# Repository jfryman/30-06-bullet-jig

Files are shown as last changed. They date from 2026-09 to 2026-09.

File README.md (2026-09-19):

# .30-06 Cartridge Laser-Marking Jig

> ### In memory of Allen Akin
> *September 8, 2026*
>
> This fixture was built to mark the cartridges for his funeral - his name on one
> side, *Spirit in the Sky* on the other. Both are engraved into the base flange,
> so the fixture carries them too. It is published here in the hope that it saves
> someone else a difficult week.
>
> *(If you are reusing this jig, `dedication` and `dedication_edge` at the top of
> `bullet-jig.scad` are yours to change or blank out.)*

A parametric 3D-printable fixture for laser-marking .30-06 Springfield cartridges
consistently, in batches, on two opposing sides.

It replaces the bed-of-rice method: cartridges sit in a cradle that is a true
negative of the SAAMI .30-06 profile, tilted so the engraved surface comes out
**level**, at a known and repeatable height above the laser bed.

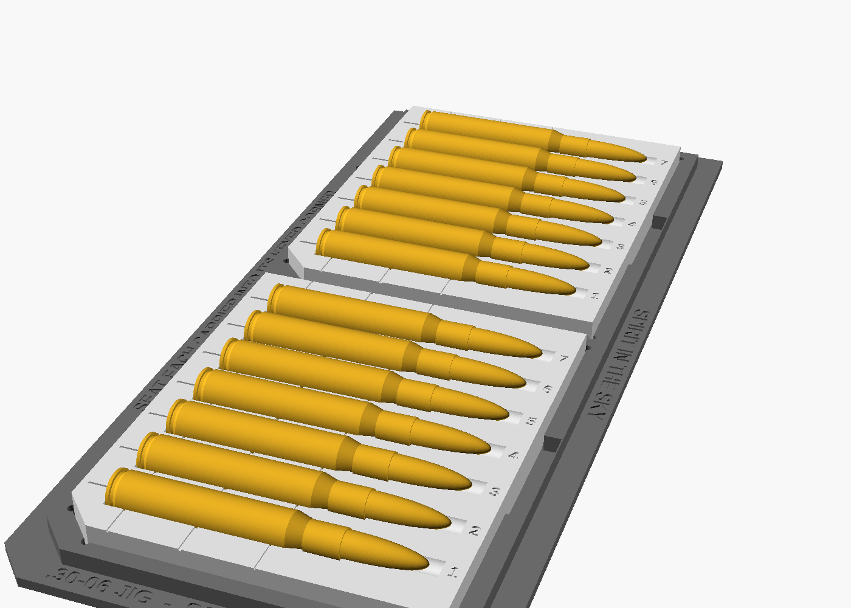
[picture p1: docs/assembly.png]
assembly


---

## How it works

Two parts:

| Part | Role |
|---|---|
| **Base** | Squared and taped to the laser bed **once**, then left alone. Holds the carriers in keyed pockets. |
| **Carrier** | Drops into the base, holds 7 cartridges, lifts out for loading, unloading and flipping. |

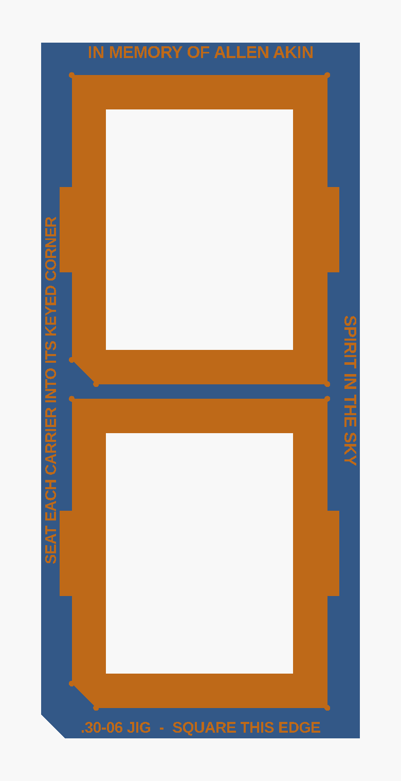
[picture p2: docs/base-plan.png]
base plan


Print several carriers. Load one set off the machine while another set is being
marked, then swap them - the keyed pockets mean a carrier can only ever seat one
way, so the laser program never has to be re-registered.

### The level-surface trick

A .30-06 case body is tapered: Ø11.964 at the head, Ø11.204 at the shoulder. Lay
one in a plain cradle and its top surface **drops 0.380 mm** across the marking
area, which walks the work in and out of focus along the length of the text.

The cradle axis is therefore tilted nose-up by exactly the body half-taper:

```
tilt = atan( (5.982 − 5.602) / (49.00 − 3.40) ) = 0.47746°
```

which cancels the taper, because `top(x) = h₀ + x·tan α + r₀ − k·x` is constant
when `tan α = k`. Measured against the supplied mesh, across the whole case body:

```
 cartridge z   true r    apex height
     3.160     5.9821      5.6585
    12.426     5.9062      5.6597
    21.692     5.8302      5.6609
    30.958     5.7542      5.6621
    40.224     5.6782      5.6634
    49.490     5.6022      5.6646

 non-flatness = 0.0061 mm   (0.380 mm if untilted)
```

Six microns - an order of magnitude below anything an FDM printer can hold, and
irrelevant next to the depth of field of a CO₂ lens.

The tilt is also what guarantees the requirement that a cartridge never nests
deeper than half: the cradle axis sits *at* the carrier top face at the head and
rises from there, so every cartridge lifts straight out with no undercut.

### Key dimensions

| | |
|---|---|
| Marking surface above the carrier top face | **5.660 mm** |
| Marking surface above the laser bed | **18.660 mm** |
| Usable marking window | **6 – 46 mm** from the case head (40 mm) |
| Nest pitch | 16.000 mm |
| Cradle clearance | 0.35 mm radial |

The marking window and its centreline are engraved into the carrier as reference
lines. They cross the cradles, so they read as dashes between nests.

---

## Printing

Prusa XL, PLA, **no supports** - the cradle is a surface of revolution opening
upward, so the model is overhang-free by construction.

| File | Size | Notes |
|---|---|---|
| `stl/carrier-7nest.stl` | 104 × 126 × 10 mm | Print 4–8. Two fit side by side on the XL. |
| `stl/base-14up.stl` | 130.8 × 285.6 × 8 mm | 2 carriers, 14 cartridges per load |
| `stl/base-28up.stl` | 241.6 × 285.6 × 8 mm | 4 carriers, 28 per load - still fits both machines |
| `stl/spray-stand-7nest.stl` | 185 × 33 × 39 mm | Clear-coat drying stand - holds 7 nose-down. See [Clear-coating](#clear-coating). |
| `stl/display-plate-17up.stl` | 212.9 × 77.6 × 9 mm | Drawer organizer - one row of 17 casings that others stack on. See [Displaying the casings](#displaying-the-casings). |
| `stl/display-plate-top.stl` | 271.1 × 144.1 × 9 mm | Chest-top display - two rows of 21, multi-color. See [Displaying the casings](#displaying-the-casings). |

* 0.2 mm layers, 3 perimeters, 15–20 % gyroid infill.
* **Brim on the base.** It is a large thin plate and wants to lift at the corners;
  it has to sit dead flat on the bed.
* Print carriers exactly as modelled, cradles facing up.
* PLA is fine - nothing here gets hot. PETG if you would rather it not scorch.

Both bases fit the Prusa XL's 360 × 360 bed and the xTool P2's 600 × 308 bed. On
the P2 the cartridges run along the 600 mm axis, so the text rasters along the
fast axis and the nests spread across the 308 mm axis.

---

## Setting up on the xTool P2

1. **Square the base** to the gantry using its long straight edge - the flange is
   engraved `SQUARE THIS EDGE`. Tape it down through the flange, outside the walls.
2. **Do not trust nominal coordinates.** A 126 mm PLA part shrinks by a few
   tenths, so the real nest pitch will not be exactly 16.000 mm. Jog the red dot
   to the engraved centreline tick on nest 1 and on nest 7, and derive the pitch
   from the actual printed part. This is the single most important setup step.
3. **Set focus from the marking surface**, nominally 18.660 mm above the bed.
   Verify it on the real thing with calipers - an over-extruded cradle will hold
   the cartridges slightly high.
4. Centre the text on the heavy engraved line, 26 mm ahead of the case head.

---

## Running a batch

1. **Spray the cartridges off the jig**, on a rack, and let them dry. Spraying
   them in the carriers just coats the carriers, which will then mark too.
2. Load carriers, seating every cartridge back against the head stop and every
   carrier into its keyed corner.
3. Run side one on the whole load.
4. Lift the carriers out, roll each cartridge 180° by eye so the first marking
   faces down, reseat.
5. Run side two.
6. Swap in the pre-loaded carriers and unload the finished set while the machine
   is already working on the next.

At 28-up, 150 cartridges is about 6 loads per side.

> On the flip: rolling by eye is good to a few degrees, which is invisible on a
> round cartridge. If you want it exact, engrave both sides in a single program
> with the cartridge rotated between two fixed stops - but for 150 pieces on a
> deadline, by eye is the right call.

---

## Clear-coating

Once both sides are marked, the cartridges get a protective clear topcoat. The
**spray stand** (`spray-stand.scad`, its own model) holds a carrier's worth
**nose-down**, so a single rotating pass covers the whole circumference - both
marked faces at once, no flip-and-redry.

Each round drops nose-first into a bore. The **shoulder** catches on the bore lip
as a self-centring stop - it seats at ~52 mm from the head, just past the 46 mm
marking window, so nothing coating-critical is touched - while the neck stays
guided in the bore below. The head and the full marking window stand up in free
air; the bullet tip hangs through the deck into the open skirt to drain and dry
without touching anything.

Nose-down on purpose: a round balanced head-down on its rim ring is a tall
inverted pendulum and tips at a touch. Hanging by the shoulder with the neck
guided is stable and self-righting.

```bash
openscad -D 'part="stand"' -o stl/spray-stand-7nest.stl spray-stand.scad
```

Prints flat, base down, **no supports** - the funnel and bore open upward. If a
round wobbles, drop `neck_clr`; the skirt height sizes itself so the tip always
clears the bench.

---

## Displaying the casings

For handing the fired casings out as party favours, the **display plate**
(`display-plate.scad`, its own model) is an organizer that carries casings on
their sides. Because a row sits in fixed cradles, more casings **nest in the
valleys between them** and the pile self-stacks into an open pyramid - cannonball
fashion. One model, two footprints via `variant`:

| `variant` | Fits | Holds |
|---|---|---|
| `drawer` (default) | Mini tool-chest **drawer**, 8.5″ wide | one row of **17** |
| `top` | Tool-chest **top**, 10¾″ × 5¾″ | two rows of **21** |

Both are sized to a **[Husky 10 in. Mini Portable Tool Box with 2
Drawers](https://www.homedepot.com/p/Husky-10-in-Army-Green-Metal-Mini-Portable-Tool-Box-with-2-Drawers-690-004-0111/339556529)**
(Home Depot Model # 690-004-0111, Internet # 339556529, Store SKU # 1014987061):
the `drawer` plate to its 8.5″-wide drawers, the `top` plate to its 10¾″ × 5¾″
lid. For a different chest, measure yours and set the footprint at the top of
`display-plate.scad`.

*(The lid closes over an 8 mm inward lip on every edge; the top variant holds the
casings back from it so the lid still shuts. On the 5¾″ (short) axis the two rows
nearly meet in the middle to clear that lip - the depth is the tight dimension,
so keep the plate centred in the well.)*

Two ideas keep the base tidy:

* **Head-to-tail.** A tapered case body laid all one way wedges the stack and
  collides at the rim. Laid head-to-tail, each pair meets fat-body-to-fat-body,
  the pitch is the body diameter, and the valleys run level for the next layer.
  On the drawer the engraved nest numbers zig front/back to cue the lay; the top
  drops the numbers and instead carries **IN MEMORY OF ALLEN AKIN** on the front
  margin and **SPIRIT IN THE SKY** on the back - the way his cartridges carried
  them on opposite sides.
* **A loose fit, on purpose.** These come in and out by hand, so the cradle wraps
  only the lower half (`sink = 0`) and a casing drops **straight in**. Clearance
  is sized to swallow print shrink: a test print came out ~1 mm short on the
  channel, so `axial_clr` leaves the channel comfortably longer than the casing.

```bash
openscad -D 'part="plate"'                     -o stl/display-plate-17up.stl  display-plate.scad
openscad -D 'part="plate"' -D 'variant="top"'  -o stl/display-plate-top.stl   display-plate.scad
```

For the top plate, a ready-to-print slicer project is included:
**`stl/display-plate-top.3mf`**, sliced for the **Original Prusa XL** (multi-tool,
0.4 mm nozzle) as a **multi-color** print - the plate body in one filament and the
two engraved dedications in a contrasting colour, so *In Memory of Allen Akin* and
*Spirit in the Sky* read against the plate. Slice `stl/display-plate-top.stl` for
any other printer.

If a casing still binds, it is a slop problem, not a geometry one - raise
`round_clr` (radial) or `axial_clr` (length). Set `casing_len` to your measured
brass; the render echoes the nominal channel length so you can check it against
calipers. Prints flat, base down, **no supports** - the cradles open upward.

---

## Parameters

Everything is driven from the top of `bullet-jig.scad`.

```bash
openscad -D 'part="carrier"'              -o stl/carrier-7nest.stl bullet-jig.scad
openscad -D 'part="base"'                 -o stl/base-14up.stl     bullet-jig.scad
openscad -D 'part="base"' -D 'pockets_x=2' -o stl/base-28up.stl    bullet-jig.scad
```

The ones worth touching:

| Parameter | Default | |
|---|---|---|
| `clearance` | `0.35` | Raise to `0.50` for fire-formed (once-fired) cases |
| `nest_count` | `7` | Cartridges per carrier |
| `pockets_x`, `pockets_y` | `1`, `2` | Carrier pockets in the base |
| `nest_pitch` | `16` | Centre-to-centre spacing |
| `dedication` | `"IN MEMORY OF ALLEN AKIN"` | Engraved on the base flange; `""` omits it |
| `dedication_edge` | `"SPIRIT IN THE SKY"` | Engraved on the long flange; `""` omits it |

`part` may be `carrier`, `base`, `both`, `demo` (shows cartridges in place) or
`none`.

### Verification

`verify.scad` intersects the supplied `Cartridge.stl` - the real mesh, not the
transcribed profile - against the cradle at its nominal position. The result must
be empty; anything else means the cradle is cut too tight somewhere.

```bash
openscad -o /dev/null verify.scad     # expect: "Current top level object is empty."
```

---

## Safety

Mark **fired brass or inert dummy rounds only.** Do not put live ammunition under
a laser - primers and propellant do not care that the beam is only meant to reach
the case wall.

---

## Credits

The cartridge profile this fixture is cut against was measured from
`Cartridge.stl`, derived from:

> **[".30-06 Springfield"](https://www.printables.com/model/101907-30-06-springfield)**
> by **[is-serp](https://www.printables.com/@isserp)**, licensed
> **[CC BY 4.0 International](https://creativecommons.org/licenses/by/4.0/)**.

The measured profile was cross-checked against published SAAMI .30-06 Springfield
dimensions (rim Ø12.014, body Ø11.964 → Ø11.204, neck Ø8.634, COAL 84.84) before
being used to cut the cradle.

If you publish a remix of this jig, carry that credit forward - CC BY requires it,
and it costs you one line.

## License

| | |
|---|---|
| This jig (`bullet-jig.scad`, `spray-stand.scad`, `display-plate.scad`, `verify.scad`, `stl/`, docs) | [CC BY 4.0](LICENSE) |
| `Cartridge.stl` | CC BY 4.0, © is-serp - see Credits above |

Use it, sell prints of it, modify it; just keep the attribution. To publish under
different terms, replace `LICENSE` and set the license field on your Printables
listing to match - but note you cannot relicense `Cartridge.stl` itself.

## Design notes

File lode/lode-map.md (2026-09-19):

# Lode Map

Index of all lode files. Start here.

```mermaid
flowchart TB
    ROOT["lode/"] --> S["summary.md"]
    ROOT --> T["terminology.md"]
    ROOT --> P["practices.md"]
    ROOT --> PL["plans/"]
    ROOT --> G["geometry/"]
    ROOT --> F["fixture/"]
    ROOT --> PR["process/"]
    ROOT --> PB["publishing/"]
    G --> G1["cartridge-profile"]
    G --> G2["levelling-tilt"]
    G --> G3["lift-out-invariant"]
    F --> F1["carrier"]
    F --> F2["base-tray"]
    F --> F3["registration"]
    F --> F4["spray-stand"]
    F --> F5["display-plate"]
    PR --> PR1["printing-and-machines"]
    PR --> PR2["laser-setup-and-batch"]
    PR --> PR3["verification"]
    PB --> PB1["licensing"]
```

## Top level

| File | Contents |
|---|---|
| [summary.md](summary.md) | One-paragraph snapshot of the whole project |
| [terminology.md](terminology.md) | Cartridge anatomy, fixture parts, process terms |
| [practices.md](practices.md) | Patterns this project holds to |
| [plans/roadmap.md](plans/roadmap.md) | Open work and pending decisions |
| `tmp/` | Session scraps. Git-ignored. |

## geometry/ - the shape of the cavity

| File | Contents |
|---|---|
| [geometry/summary.md](geometry/summary.md) | Domain index, the two invariants |
| [geometry/cartridge-profile.md](geometry/cartridge-profile.md) | `CART` table, datum scheme, deliberate relief |
| [geometry/levelling-tilt.md](geometry/levelling-tilt.md) | The nose-up tilt that cancels body taper |
| [geometry/lift-out-invariant.md](geometry/lift-out-invariant.md) | Why the axis never drops below the top face |

## fixture/ - the physical parts

| File | Contents |
|---|---|
| [fixture/summary.md](fixture/summary.md) | Domain index, part sizes |
| [fixture/carrier.md](fixture/carrier.md) | Nest block: features, markings, invariants |
| [fixture/base-tray.md](fixture/base-tray.md) | Tray: pockets, keying, flange engraving |
| [fixture/registration.md](fixture/registration.md) | Fiducials, the measure-don't-assume doctrine |
| [fixture/spray-stand.md](fixture/spray-stand.md) | Nose-down shoulder-seat stand for clear-coating marked rounds |
| [fixture/display-plate.md](fixture/display-plate.md) | Scalloped casing display; drawer and chest-top (memorial) variants, head-to-tail rows |

## process/ - model to marked cartridges

| File | Contents |
|---|---|
| [process/summary.md](process/summary.md) | Domain index, the pipeline |
| [process/printing-and-machines.md](process/printing-and-machines.md) | Machine budgets, print settings, STL export |
| [process/laser-setup-and-batch.md](process/laser-setup-and-batch.md) | P2 setup, batch workflow, safety |
| [process/verification.md](process/verification.md) | `verify.scad` contract, first-article check |

## publishing/ - licence and distribution

| File | Contents |
|---|---|
| [publishing/summary.md](publishing/summary.md) | Where it lives, repo layout |
| [publishing/licensing.md](publishing/licensing.md) | Two licences, attribution obligations, dedication |

## Reading order for a fresh session

1. [summary.md](summary.md) and [terminology.md](terminology.md)
2. [geometry/levelling-tilt.md](geometry/levelling-tilt.md) - the one idea
   everything else serves
3. [fixture/registration.md](fixture/registration.md) - the one number setup
   depends on
4. [plans/roadmap.md](plans/roadmap.md) - what is open

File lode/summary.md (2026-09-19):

# Project Summary

A parametric OpenSCAD fixture for laser-marking .30-06 Springfield cartridges in
batches, on two opposing sides. It exists to replace a bed-of-rice proof of
concept with something repeatable enough to run 100-150 pieces. The fixture is
two parts: a **base** that is squared and taped to the laser bed once and left
alone, and **carriers** that drop into keyed pockets in the base, each holding 7
cartridges, lifting out for loading, unloading and flipping. The defining design
problem is that a .30-06 case body is tapered, so a cartridge lying in a plain
cradle presents a marking surface that drops 0.380 mm along its length; the
cradle axis is therefore tilted nose-up by exactly the body half-taper, which
cancels the taper and holds the marking surface level to 0.0061 mm. Target
machines are an xTool P2 (600 x 308 bed) and a Prusa XL (360 x 360). A separate
**spray stand** (`spray-stand.scad`) is the downstream companion: it holds a
carrier's worth of marked rounds nose-down, hung by the shoulder in guide bores,
so a rotating pass of clear coat covers both marked faces at once. A stand-alone
**display plate** (`display-plate.scad`) is the end of the line: a scalloped base
that holds finished empty casings on their sides, head-to-tail, so the pile stays
tidy. It has two footprints for a Husky 10 in. mini chest - a drawer organiser
(one row of 17) and a memorial lid-top (two rows of 21, engraved in Allen's
memory). The work is published at github.com/jfryman/30-06-bullet-jig under CC BY
4.0, and is dedicated to Allen Akin.

See [lode-map.md](lode-map.md) for the full index.

Domain entry points:
- [geometry/summary.md](geometry/summary.md) - profile, tilt, and the invariants
- [fixture/summary.md](fixture/summary.md) - carrier and base parts
- [process/summary.md](process/summary.md) - print, verify, set up, run
- [publishing/summary.md](publishing/summary.md) - licence and attribution

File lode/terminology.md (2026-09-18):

# Terminology

Domain language for this project. Cartridge anatomy first, then fixture parts.

## Cartridge anatomy

- **Cartridge** - the complete round: case + primer + powder + bullet. The whole
  thing is what gets marked. Colloquially called "the bullet" in conversation.
- **Bullet** - strictly, only the projectile seated in the case mouth. Not the
  marking surface.
- **Case** - the brass body. Its outer wall is the marking surface.
- **Case head** - the flat base of the cartridge. The axial datum for everything.
- **Rim** - the flange at the head, O12.014 on .30-06. Rides the rim bore.
- **Extractor groove** - the narrow turned groove just ahead of the rim.
  Deliberately not reproduced in the cradle; see
  [geometry/cartridge-profile.md](geometry/cartridge-profile.md).
- **Case body** - the long, slightly tapered section, O11.964 -> O11.204. This
  is the only part that gets marked.
- **Shoulder** - the cone where the body steps down to the neck, at z=49.
- **Neck** - the parallel section gripping the bullet, O8.634.
- **Case mouth** - the open end of the neck, z=63.35.
- **Ogive** - the curved nose of the bullet.
- **COAL** - Cartridge Overall Length. 84.84 mm max for .30-06 per SAAMI.
- **SAAMI** - the US standards body whose published dimensions the measured
  profile was cross-checked against.
- **Fire-formed** - a case that has been fired, so expanded to chamber size.
  Slightly larger than factory; needs more cradle clearance.
- **Headstamp** - markings on the case head. Not used for indexing.

## Fixture parts

- **Base** (or base tray) - the part taped and squared to the laser bed once,
  then left alone. Holds carriers in keyed pockets.
- **Carrier** - the removable block holding 7 cartridges, dropping into a base
  pocket. Several are printed so one loads while another is under the laser.
- **Nest** - one cartridge position in a carrier.
- **Cradle** - the cavity of one nest; a true negative of the cartridge profile.
- **Apex line** - the topmost line along the cartridge, where the beam lands.
  Holding this level is the point of the tilt.
- **Marking window** - the usable span of case body, 6-46 mm from the case head.
- **Head stop** - the wall the case head butts against; the axial datum.
- **Rim bore** - the straight section of cradle the rim rides in.
- **Eject slot** - through-slot at the neck; push a round up from underneath.
- **Tip channel** - relief past the bullet nose so an over-long round cannot bind.
- **Key corner** - the 45 degree chamfer that makes a carrier seat one way only.
- **Flange** - the flat border of the base, for taping down and squaring.
- **Fiducial / tick** - engraved centreline mark used to align the laser to the
  real printed part rather than to nominal coordinates.
- **Pitch** - nest centre-to-centre spacing, 16.000 mm nominal.

## Process

- **Laser spray / marking spray** - CerMark-type coating that bonds to metal
  under a CO2 beam. Applied before loading, never on the jig.
- **Clear coat / topcoat** - a protective clear finish rattle-canned over the
  finished marks, after marking. A different coating at a different step from the
  marking spray; applied with the round in the spray stand, not the jig.
- **Spray stand** - the companion fixture that holds a carrier's worth of rounds
  nose-down for clear-coating. See
  [fixture/spray-stand.md](fixture/spray-stand.md).
- **Display plate** - a stand-alone display base (not a pipeline fixture) that
  holds finished empty cases lying on their sides in a scalloped row inside a
  tool-chest drawer. See [fixture/display-plate.md](fixture/display-plate.md).
- **Head-to-tail** - laying cases in alternating directions so each adjacent
  pair's radii sum to a constant along the tapered body; gives level valleys and
  packs tighter than one direction (which would collide at the rim). The display
  plate's base row is laid this way.
- **Open pyramid** - the display stacking scheme: the plate fixes only the base
  row; each further layer nests by gravity in the valleys of the layer below.
- **Shoulder seat** - how the spray stand holds a round: dropped nose-first, the
  shoulder cone catches on a bore lip while the neck is guided in the bore below.
  Nose-down because nose-up (rim ring, no upper guide) is too tippy.
- **Fast axis** - the laser's raster direction (X on the P2). Text runs along it.
- **First article** - the first part off the printer, checked before a batch.

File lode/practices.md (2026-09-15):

# Practices

Patterns this project holds to. Most were paid for once already.

## Verify against the real artefact, not your transcription

`CART` is a hand-transcribed profile. The test that matters intersects the
**actual `Cartridge.stl` mesh** against the cradle, so a typo in the table is
caught by geometry rather than by proofreading. See
[process/verification.md](process/verification.md).

Corollary: when measuring a coarse mesh, evaluate at its **true vertex rings**.
Sampling arbitrary narrow bands returns empty sets and looks like a code bug.

## Manifold is not correct

A valid, watertight, "Simple: yes" render proves only that the solid is
well-formed. An eject slot cutting sideways into neighbouring nests passed every
automated check. **Render an image and look at it** after any change to
placement, rotation, or text.

## Derive constants; never type them

```openscad
body_k = (5.982 - 5.602) / (49.00 - 3.40);
tilt   = atan(body_k);        // not 0.4775
```

If the profile changes, the tilt follows. A typed-in tilt silently decouples from
the geometry it is supposed to cancel.

## Coordinate-frame discipline

Two traps, both hit once:

- **Cartridge z is not carrier X.** They differ by `head_margin`. Convert.
- **After `rotate([0, 90 - tilt, 0])`, local +X is "down"**, not local Y. Work
  out the axis mapping before writing a cube into a rotated frame.

## Empirical alignment beats nominal coordinates

Printed parts shrink. Rather than chase tolerances, engrave fiducials and align
the machine to the **real part**. See
[fixture/registration.md](fixture/registration.md). The corollary is that every
fiducial needs its nominal value documented so a measured deviation is
meaningful.

## Cheap checks gate expensive ones

Order any check procedure so a failure at step 1 saves the work of steps 2-6.
Likewise, structure parts so a likely failure is a **cheap** reprint: `clearance`
and `pocket_clr` problems both reprint the carrier only, never the base.

## Relieve what you cannot print reliably

The extractor groove is not reproduced. A printed bump inside a 0.8 mm groove
would rock the cartridge and destroy the levelness the design depends on.
Prefer a clean relieved datum over a faithful copy of a feature FDM cannot hold.

## Parameterise what a downstream user would change

The dedication is a parameter, not a string literal, because the model is
published for others. Same for `clearance`, `nest_count`, `pockets_*`.

## Assert only what you verified

Do not state a licence version you have not seen; do not quote print times you
have not measured. Fetch canonical legal text rather than reproducing it.

## Build hygiene

- Export with `--export-format=binstl`. ASCII STL is ~3.5x larger.
- Keep the `echo()` dimension block current; it is a free regression check on
  every render.
- Regenerate **all** STLs after a source change, even parts you believe are
  unaffected.

## Related

- [summary.md](summary.md)
- [lode-map.md](lode-map.md)

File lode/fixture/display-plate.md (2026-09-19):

# Display plate

A loose organizer, not a pipeline fixture and not a precision cradle. Fired empty
**casings** (no bullet, ~63 mm to the mouth) are dropped on their sides into a
scalloped plate. Each cradle holds one casing; a row seats a base row, and
further casings nest in the valleys between them so the pile self-stacks into an
**open pyramid** (`layer_rise = sqrt(3) * r_centre` ~ 9.95 mm per layer). Source
is `display-plate.scad` at the repo root; one model, two footprints via `variant`.

These are **party favours**: the aim is tidy organisation, so every casing must
drop in and lift out freely - the opposite instinct from the jig. It shares only
the cartridge profile (the [CART](../geometry/cartridge-profile.md) table,
truncated at the case mouth).

## Two variants (`variant`)

| `variant` | Footprint | Rows x count | STL |
|---|---|---|---|
| `drawer` | 8.5" drawer -> `drawer_w - 2*fit_clr` wide, depth snug to one row | 1 x 17 | `stl/display-plate-17up.stl` |
| `top` | 10.75 x 5.75" chest top (`top_w` x `top_d`), minus `pullback` per edge | 2 x 21 | `stl/display-plate-top.stl` |

Both footprints are sized to a **Husky 10 in. Mini Portable Tool Box with 2
Drawers** (Home Depot Model # 690-004-0111, Internet # 339556529, Store SKU #
1014987061): the drawer plate to its 8.5" drawers, the top plate to its
**10.75 x 5.75"** lid (measured off the real chest).

`drawer` is the default so a bare render reproduces the shipped drawer plate.
`stack_gap` differs (0.60 drawer for finger room, 0.25 top to make the count).

```mermaid
flowchart TB
    V{variant} -->|drawer| DR["8.5 in drawer<br/>1 row x 17, nests into a pyramid"]
    V -->|top| TP["10.75 x 5.75 in lid<br/>2 rows x 21 = 42, single layer"]
```

### The lid lip - why the top is 2 x 21

The lid closes over an inward **lip, `lid_lip = 8` mm on every edge**. Anything
protruding under it stops the lid, so the casings are held `keepout = lid_lip +
lip_clr` back from the lid opening (the plate itself still fills the well). Two
asserts (`lip_gap_x`, `lip_gap_y`) prove the brass clears the lip; the `echo`
reports the margin.

- **Width (10.75", roomy):** count is maximised inside the keepout -> **21** per
  row, clearing the lip by ~4.6 mm.
- **Depth (5.75", tight):** two rows of 63.25 mm casings need 126.5 mm; the clear
  span inside the lip is only ~130 mm. So the rows **pack tight** (`row_pitch =
  casing_len + row_gap`, ~0.5 mm gap, channels may merge at the centre) and centre
  on the lid, clearing the lip by only **~1.5 mm**. `pullback` is small (1 mm) so
  the plate cannot slide far and eat that margin. A single row is the safe
  fallback if the depth margin is unacceptable.

## Loose by design - the slop knobs

The first cut gripped too hard to accept a casing without angling it in. Fixed:

- **`sink = 0`.** The cradle wraps only the **lower half** of the casing, so the
  opening at the surface is the full casing diameter and it drops **straight
  down**. Any positive `sink` grips past the equator (retention, but you must snap
  it in) - keep 0 for party favours.
- **Clearance sized to swallow print shrink.** `round_clr = 0.50` radial;
  `axial_clr = 2.00` extends the channel to **65.55 mm** so it clears the measured
  **63.25 mm** casing by 2.3 mm. A test print came out ~1 mm short of nominal on
  channel length (~1.2 % shrink), so the real margin is ~1.3 mm. Raise
  `round_clr` / `axial_clr` if a printer runs tighter; an assert guards
  `channel_len >= casing_len + 0.5`. The `echo` reports the nominal length for a
  caliper check.

## What keeps a row uniform

**Alternating head-to-tail** cancels the body taper (r 5.982 -> 5.602): each pair
meets fat-body-to-fat-body, the pitch is the body diameter, and the valleys run
level. Packs tighter than one-way (which collides at the rim, O12.014). An assert
guards `pitch >= contact_d`.

**A symmetric negative.** Each cradle is the casing profile of revolution grown by
`round_clr`, end caps pushed out by `axial_clr/2`, laid along Y and unioned with
its mirror (`cradle_cut(cy)`), so a casing seats level whichever way it points.

## Layout

- `count` across the width: drawer maximises inside the side walls, top maximises
  inside the lid keepout; then centred (`nest_cx`).
- Rows front-to-back (`row_cy(j)`, `row_pitch`): the drawer's single row sits at
  `end_margin`; the top's two rows pack tight (`casing_len + row_gap`) and centre
  on the lid. An assert stops the casings themselves overlapping.
- `plate_th = sink + (rim_r + round_clr) + floor` ~ 9.0 mm (thin, since sink 0).

## Markings (`markings` -> `drawer_markings` / `top_markings`)

- **Drawer**: casing numbers in the flat band beyond each casing's head end,
  alternating so they zig and cue the head-to-tail lay; `title` on the front
  face, `dedication` on the back.
- **Top**: a memorial display - **no numbers**. The two rows nearly meet at the
  centre on the short lid, so there is no centre band; `dedication` engraves on
  the **front** margin and `dedication_edge` on the **back** ("IN MEMORY OF ALLEN
  AKIN" / "SPIRIT IN THE SKY", the pair the funeral cartridges carried on opposite
  sides). Engraved (recessed), so being near the edge does not foul the lid lip.

## Print

Flat, base down, **no supports** - the cradles open upward.

A ready-to-print slicer project ships for the top variant:
`stl/display-plate-top.3mf`, a PrusaSlicer project for the **Original Prusa XL**
(multi-tool, 0.4 mm nozzle), sliced **multi-colour** (cream body, orange
lettering) so the two dedications print in a contrasting filament. It carries the
corrected `variant="top"` mesh; the `.stl` beside it is for any other printer.

## Related

- [../geometry/cartridge-profile.md](../geometry/cartridge-profile.md) - the
  `CART` profile this mirrors (truncated at the mouth) and the uniform-offset
  doctrine (here relaxed for a loose fit)
- [spray-stand.md](spray-stand.md) - the other stand-alone companion `.scad`

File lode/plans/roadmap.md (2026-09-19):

# Roadmap

Current open work. Delete items as they close; this file is state, not history.

The marking jig, the spray stand, and both display plates are built and validated
in use. What is left is publishing and one standing throughput option.

## Not started

- **Printables listing.** The GitHub repo is live; the Printables publication is
  not. Licence and attribution obligations are recorded in
  [../publishing/licensing.md](../publishing/licensing.md).

## Available but not committed

- **28-up base.** `stl/base-28up.stl` exists (`pockets_x = 2`, 241.6 x 285.6) and
  fits both machines. Doubles throughput per load at the cost of a larger base
  print. Default remains the 14-up base to keep the critical-path print short.

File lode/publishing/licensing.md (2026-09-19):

# Licensing and Attribution

```mermaid
flowchart TB
    UP[".30-06 Springfield<br/>by is-serp<br/>CC BY 4.0"] -->|source mesh| CART["Cartridge.stl<br/>stays CC BY 4.0"]
    CART -->|profile measured from| JIG["bullet-jig.scad + STLs<br/>CC BY 4.0"]
    JIG --> OBL["Attribution obligation<br/>carries forward"]
```

## Two licences, one repo

| Covers | Licence |
|---|---|
| `bullet-jig.scad`, `spray-stand.scad`, `display-plate.scad`, `verify.scad`, `stl/`, `docs/` | CC BY 4.0 |
| `Cartridge.stl` | CC BY 4.0, (c) is-serp |

`LICENSE` holds the canonical CC BY 4.0 legal text, fetched from
`creativecommons.org/licenses/by/4.0/legalcode.txt` rather than retyped.

## The upstream attribution

The cartridge profile was measured from a third-party mesh:

> **".30-06 Springfield"** by **is-serp**
> https://www.printables.com/model/101907-30-06-springfield
> Licensed CC BY 4.0 International

Recorded in three places, all of which must stay in sync: the README Credits
section, the README licence table, and the `bullet-jig.scad` header.

## Contracts

- **`Cartridge.stl` cannot be relicensed.** If the project licence ever changes,
  the mesh stays CC BY 4.0 and the attribution stays. The README licence table
  says so explicitly.
- Any remix must carry the is-serp credit forward - CC BY requires it.
- The Printables listing's licence field must match `LICENSE`.

## Dedication

The fixture is dedicated to **Allen Akin**, who died 8 September 2026; it was
built to mark cartridges for his funeral, his name on one side and *Spirit in
the Sky* on the other. The dedication appears in the README, the
`bullet-jig.scad` header, and engraved into two flanges of the base.

It is **parameterised, not hardcoded**, so anyone reusing the jig can substitute
their own words or blank it:

```openscad
dedication      = "IN MEMORY OF ALLEN AKIN";   // top flange, "" omits
dedication_edge = "SPIRIT IN THE SKY";         // right flange, "" omits
```

## Lessons learned

Do not assert a licence version you have not seen. Printables' API reports only
`"abbreviation": "CC-BY"` with no version; the "4.0 International" came from the
model page itself. For legal text, fetch the canonical copy rather than
reproducing it from memory.

Printables blocks scripted page fetches (Cloudflare 403), but its GraphQL API
answers anonymously:

```bash
curl -sS 'https://api.printables.com/graphql/' \
  -H 'content-type: application/json' -H 'origin: https://www.printables.com' \
  --data '{"query":"query($id:ID!){print(id:$id){name license{name abbreviation} user{publicUsername}}}","variables":{"id":"101907"}}'
```

## Related

- [../geometry/cartridge-profile.md](../geometry/cartridge-profile.md)
- [summary.md](summary.md)

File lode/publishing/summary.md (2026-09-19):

# Publishing

The project is published as an open model. Two obligations attach to that: the
upstream mesh's licence, and the project's own.

- [licensing.md](licensing.md) - licences, attribution, and what may be
  relicensed

## Where it lives

| | |
|---|---|
| Git remote | `git@github.com:jfryman/30-06-bullet-jig.git` (branch `master`) |
| Printables | not yet listed |

Pushes go over SSH. `gh` is not authenticated on this machine, and the HTTPS
remote cannot authenticate non-interactively.

## Repo layout

```
bullet-jig.scad     parametric marking jig, base + carrier
spray-stand.scad    clear-coat drying stand (own model)
display-plate.scad  casing display, drawer + chest-top variants (own model)
verify.scad         automated fit test, must render empty
Cartridge.stl       reference mesh (third-party, CC BY 4.0)
stl/                carrier-7nest, base-14up, base-28up, spray-stand-7nest,
                    display-plate-17up, display-plate-top (+ .3mf for the XL)
docs/               renders (assembly, base plan, carrier)
lode/               this knowledge base (lode/tmp/ is git-ignored)
LICENSE             CC BY 4.0
```

## Related

- [../process/printing-and-machines.md](../process/printing-and-machines.md)

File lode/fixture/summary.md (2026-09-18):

# Fixture

The two physical parts and how they relate.

```mermaid
flowchart TB
    BED["Laser bed"] -->|taped + squared once| BASE["Base tray<br/>130.8 x 285.6 x 8"]
    BASE -->|keyed pockets| C1["Carrier 1<br/>104 x 126 x 10"]
    BASE -->|keyed pockets| C2["Carrier 2"]
    C1 --> N["7 nests each<br/>16 mm pitch"]
    C2 --> N
    SPARE["Spare carriers<br/>loaded off-machine"] -.->|swap| BASE
```

The base never moves once taped. Carriers are consumable fixturing: print
several, load one set while another is under the laser, swap them. A separate
**spray stand** holds a carrier's worth of rounds nose-down for clear-coating
after marking; it is downstream of the base/carrier, not part of the assembly.

## Files

- [carrier.md](carrier.md) - the removable nest block
- [base-tray.md](base-tray.md) - the taped-down tray
- [registration.md](registration.md) - keying, fiducials, and why nominal
  coordinates must not be trusted
- [spray-stand.md](spray-stand.md) - nose-down shoulder-seat stand for clear-coating
- [display-plate.md](display-plate.md) - scalloped base for stacking finished
  empty casings; drawer (1 row) and chest-top (2 rows) variants

## Part sizes

| Part | Size | Config |
|---|---|---|
| `stl/carrier-7nest.stl` | 104 x 126 x 10 | `nest_count = 7` |
| `stl/base-14up.stl` | 130.8 x 285.6 x 8 | `pockets_x=1, pockets_y=2` |
| `stl/base-28up.stl` | 241.6 x 285.6 x 8 | `pockets_x=2, pockets_y=2` |
| `stl/spray-stand-7nest.stl` | 185 x 33 x 39 | `nest_count = 7` (own `.scad`) |
| `stl/display-plate-17up.stl` | 212.9 x 77.6 x 9.0 | 8.5" drawer -> 17 up, loose fit (own `.scad`) |
| `stl/display-plate-top.stl` | 271.1 x 144.1 x 9.0 | 10.75x5.75" chest top -> 2 rows of 21, multi-color (`variant="top"`) |

## Related

- [../geometry/summary.md](../geometry/summary.md) - what shapes the nests
- [../process/printing-and-machines.md](../process/printing-and-machines.md)

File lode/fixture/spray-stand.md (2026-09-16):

# Spray stand

A companion fixture, separate from the marking jig. After a batch is
laser-marked, the rounds are stood **nose-down** in the spray stand and given a
protective clear coat (a rattle-can topcoat over the CerMark marks). Source is
`spray-stand.scad` at the repo root; production STL is
`stl/spray-stand-7nest.stl`. It shares nothing with the jig but the cartridge
profile it seats against.

## Why nose-down, vertical

A loaded round is a closed cartridge (bullet seated) - it can only be held
externally. Standing it vertical means one **rotating pass coats the whole
circumference**, so both opposing marked faces are covered without a
flip-and-redry cycle a horizontal cradle would force. The
[marking window](../geometry/cartridge-profile.md) (6-46 mm from the head)
stands in free air well above the deck, fully exposed. This part does **not**
use the jig's [levelling tilt](../geometry/levelling-tilt.md) - a drying round
only has to stand still, not present a level surface.

**Nose-down, not nose-up.** A round balanced head-down on its rim ring is a tall
inverted pendulum (COM ~40 mm up over a ~12 mm base) and tips at a touch - the
first nose-up cone-seat attempt failed exactly here. Dropped nose-first into a
bore instead, the slender bullet and neck lead in and the round hangs by its
shoulder, guided along the neck, which is stable and self-righting.

## The shoulder seat

The round drops nose-first into a lead-in funnel over a straight guide bore.

```mermaid
flowchart TB
    R["Round, nose-down<br/>head + marking window up, exposed"] --> SH["Shoulder cone catches on bore lip<br/>self-centring axial stop, z 51.96 from head"]
    R --> NECK["Neck captured in guide bore below<br/>resists cocking, self-rights"]
    SH --> LIP["Funnel lip = seat, cs_depth below deck top"]
    NECK --> DRAIN["Bore runs through into the open skirt<br/>coating drains, bullet hangs free"]
```

Contract, all derived in the `.scad` from the CART shoulder/neck dimensions:
- Guide bore radius `bore_r = neck_r(4.317) + neck_clr(0.4)` = 4.717
  (O9.43). The neck (O8.634) drops through; the shoulder (widening past it)
  cannot, so it seats.
- The shoulder catches where its cone reaches `bore_r`: **z 51.96 mm from the
  head**. Two asserts guard the design: `bore_r < shoulder top r` (so it seats
  at all) and `seat_zfh > window_to(46)` (so the seat never shadows the marking
  window). If you widen `neck_clr` a lot, re-check the second assert.
- Seat is a ring on the bore lip (cone-on-edge): minimal contact, on the
  unmarked shoulder just past the window, self-centring.
- The bore runs straight through the deck into the open skirt cavity, so coating
  drains out and the bullet tip hangs free.
- Anti-tip: the neck is guided over ~11 mm of bore below the seat at 0.4 mm
  clearance -> the round can only cock ~2 degrees, and gravity re-seats it. This
  is the whole reason nose-down is stable where nose-up was not.

## Structure and print

- Single row of `nest_count = 7` seats at `nest_pitch = 26` mm.
- Deck `185 x 33 x 18`; the bore runs through it. Lifted on a skirt whose height
  is **computed** (`skirt_h`) so the bullet tip (hanging ~17.9 mm below the deck
  bottom) clears the bench by `tip_clr = 3` mm. Overall height ~38.9 mm.
- Skirt corners solid for rigidity; long sides windowed for drainage, airflow
  and finger access. Bullet tips hang in the open windowed cavity.
- Prints flat, base down, **no supports**: the funnel and bore are open upward.
- Seat numbers 1-7 on the deck front match the [carrier](carrier.md) nest
  numbers; `title` on the skirt face and `dedication` on the deck are parametric.

## Related

- [carrier.md](carrier.md) - where the rounds come from; nests numbered to match
- [../geometry/cartridge-profile.md](../geometry/cartridge-profile.md) - the
  shoulder, neck and marking-window dimensions this seats against
- [../process/summary.md](../process/summary.md) - marking spray vs. this clear
  coat are different coatings at different steps

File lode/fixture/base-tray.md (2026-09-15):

# Base Tray

Squared and taped to the laser bed **once**, then left alone. Everything
downstream is referenced off it, so its flatness is load-bearing.

## Construction

```openscad
pocket_x = carrier_len + 2 * pocket_clr;   // 104.8
pocket_y = carrier_y   + 2 * pocket_clr;   // 126.8
span_x = pockets_x * pocket_x + (pockets_x - 1) * divider;
span_y = pockets_y * pocket_y + (pockets_y - 1) * divider;
base_x = span_x + 2 * base_wall + 2 * flange;
base_y = span_y + 2 * base_wall + 2 * flange;
base_h = base_floor + pocket_depth;        // 3 + 5 = 8
```

A 3 mm floor with 5 mm walls standing 5 mm proud, plus an 8 mm flat flange all
round for taping and squaring.

```mermaid
flowchart TB
    F["Flange 8 mm<br/>tape + square here"] --> W["Wall 5 mm<br/>pocket sides"]
    W --> P["Pocket, 0.4 mm/side<br/>carrier drops in"]
    P --> FL["Floor 3 mm"]
    FL --> WIN["Window<br/>inset 14 mm"]
    WIN --> EJ["Push rounds up<br/>through carrier eject slots"]
```

## Features

- **Pockets**, one per carrier, `pocket_clr = 0.4` per side, `pocket_depth = 5`.
  The carrier is 10 mm thick, so 5 mm stands proud to grip.
- **Key corner** - 45 deg chamfer, `key_chamfer = 10`, on each pocket *and* on
  the overall outline. Breaks every symmetry, so a carrier seats one way only.
- **Corner relief** - r = 1.2 cylinders at each pocket vertex so a slightly
  bulged carrier corner cannot wedge.
- **Floor windows**, inset 14 mm. Save print time and let you push cartridges up
  from underneath through the carrier's eject slots.
- **Finger notches**, 35 mm wide in the end walls, for lifting a loaded carrier.

## Flange engraving

All four flanges are used. Engraved, never raised - raised lettering would stop
the base taping down flat.

| Flange | Text | Source |
|---|---|---|
| bottom (X) | `.30-06 JIG  -  SQUARE THIS EDGE` | fixed |
| left (Y) | `SEAT EACH CARRIER INTO ITS KEYED CORNER` | fixed |
| top (X) | `IN MEMORY OF ALLEN AKIN` | `dedication` |
| right (Y) | `SPIRIT IN THE SKY` | `dedication_edge` |

The dedication is parameterised so anyone reusing the jig can change or blank it
(`""` omits). See [../publishing/licensing.md](../publishing/licensing.md).

## Invariants

- **The base must sit dead flat.** It is a large thin plate; print with a brim.
  If a corner rocks, every height measurement below it is meaningless.
- Flange text must fit inside `base_x`. At `size = 4.5`-`5`, a ~45 character
  string overflows the 130.8 mm 14-up base. Check a top-down render after
  editing any flange string.
- Engrave, never emboss, on the flange.

## Related

- [carrier.md](carrier.md)
- [registration.md](registration.md)

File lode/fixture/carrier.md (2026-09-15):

# Carrier

The removable block holding 7 cartridges. Drops into a keyed base pocket, lifts
out for loading, unloading and flipping.

## Geometry

```openscad
carrier_y = nest_count * nest_pitch + 2 * side_margin;   // 7*16 + 14 = 126
function nest_y(i) = side_margin + nest_pitch / 2 + i * nest_pitch;
```

Size 104 x 126 x 10 mm. Top face sits **on the cartridge centreline** - that is
what makes the nest exactly half-depth.

| Feature | Extent | Purpose |
|---|---|---|
| Head stop | X = 0 .. 9.8 | Solid band; case head butts it. Axial datum. |
| Nest cradle | from X = 9.8 | Profile negative, see [../geometry/cartridge-profile.md](../geometry/cartridge-profile.md) |
| Eject slot | cartridge z 54..64 | Through-slot at the neck; push rounds up from below |
| Tip channel | cartridge z 78..88 | Relief past the nose, r = 3.0 |
| Solid band | X = 98 .. 104 | Carries the nest numbers |
| Bottom chamfer | 0.8 mm | Defeats elephant's foot so it seats flat in the pocket |

```mermaid
flowchart LR
    HS["Head stop<br/>X 0-9.8"] --> W1["Window start<br/>16"]
    W1 --> WC["Window centre<br/>36 (heavy line)"]
    WC --> W2["Window end<br/>56"]
    W2 --> EJ["Eject slot<br/>64-74"]
    EJ --> TC["Tip channel<br/>88-98"]
    TC --> NUM["Nest numbers<br/>98-104"]
```

## Engraved markings

All cut `mark_depth = 0.5` into the top face:

- **Three transverse reference lines** at 6, 26 and 46 mm from the case head
  (the heavy one at 26 is the window centre). They cross the cradles, so they
  read as **dashes between nests**.
- **A centreline tick per nest** on the head-end solid band, X = 2..8.
- **A nest number per nest** on the tip-end solid band, X ~ 101.

These exist so the laser is aligned to the real printed part. See
[registration.md](registration.md).

## Invariants

- Top face is the parting plane at the cartridge centreline. Do not thicken the
  carrier without moving the nest axis with it.
- No supports, cradles facing up - guaranteed by
  [../geometry/lift-out-invariant.md](../geometry/lift-out-invariant.md).
- Anything cut past `tip_to` must leave the X 98..104 band solid or the nest
  numbers land in mid-air. `tip_to` is in **cartridge z**; carrier X is
  `head_margin + z`, so `tip_to = 88` puts the channel end at X = 98.

## Lessons learned

Cartridge z and carrier X differ by `head_margin`. Conflating them once pushed
the tip channel 4 mm past the end face. Always convert.

## Related

- [base-tray.md](base-tray.md)
- [registration.md](registration.md)

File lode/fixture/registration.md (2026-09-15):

# Registration and Fiducials

How the laser finds the work, and the one measurement the whole setup depends on.

## The doctrine

> **Never program nominal coordinates. Measure the printed part.**

A 126 mm PLA carrier shrinks by a few tenths, so its real nest pitch is not
16.000 mm. Worse, the shrinkage is in the *carrier itself*, so no amount of
precision in the base can correct it. The fix is to make alignment empirical:
engraved fiducials on the carrier, which the operator jogs the red dot to.

```mermaid
flowchart TB
    KEY["Keyed corner<br/>one seating orientation"] --> SEAT["Carrier seated<br/>pushed into the key"]
    SEAT --> T1["Jog to nest 1 tick<br/>nominal Y = 15.000"]
    SEAT --> T7["Jog to nest 7 tick<br/>nominal Y = 111.000"]
    T1 --> SPAN["Measured span<br/>nominal 96.000"]
    T7 --> SPAN
    SPAN --> DIV["Divide by 6 gaps"]
    DIV --> PITCH["REAL pitch -> program"]
```

## The numbers

| | |
|---|---|
| nest 1 centreline tick | Y = 15.000 mm from the carrier edge |
| nest 7 centreline tick | Y = 111.000 mm |
| span | 96.000 mm across **6** gaps |
| window centre (heavy line) | X = 36 mm from the carrier head-end face |

Derived from `nest_y(i) = side_margin + nest_pitch/2 + i*nest_pitch`, so
`nest_y(0) = 15` and `nest_y(6) = 111`.

## The off-by-one

**Divide the span by 6, not 7.** Seven nests, six gaps. Dividing by the nest
count instead of the gap count yields 13.71 mm and puts the program 2.67 mm out
per nest - a miss, not a rounding error, and one that survives a casual check
because the wrong answer still looks plausibly like "about 16".

## Registration chain

- **Rotation and translation** come from the keyed pocket. Always seat a carrier
  *into* its key corner; the pocket has 0.4 mm/side of clearance, so consistency
  comes from always pushing the same way, not from the fit being tight.
- **Y (across nests)** is the critical direction: error here walks the text off
  the apex crown. It is absorbed by measuring the tick span.
- **X (along the cartridge)** is tolerant; error just shifts text along the case.
- **Z** is `18.660 mm` above the bed, verified with calipers, not assumed.

## Flip registration

The 180 degree flip for side two is done **by eye** - roll the round until the
first marking faces down. Deliberate: rolling is accurate to a few degrees, which
is invisible on a round cartridge, and any positive indexing scheme adds a part
to handle 300 times. The cradle lets the round spin freely about its own axis,
which is what makes this work.

## Related

- [carrier.md](carrier.md) - where the fiducials live
- [base-tray.md](base-tray.md) - the keyed pockets
- [../process/laser-setup-and-batch.md](../process/laser-setup-and-batch.md)

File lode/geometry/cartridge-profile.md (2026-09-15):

# Cartridge Profile

The cradle is cut as a true negative of a measured .30-06 profile, held in the
`CART` table in `bullet-jig.scad`.

## The table

Columns are `[ axial position from case head, radius, extra local relief ]`.
All values mm. The profile was measured off `Cartridge.stl` and cross-checked
against published SAAMI .30-06 dimensions (rim O12.014, body O11.964 -> O11.204,
neck O8.634, COAL 84.84).

```openscad
CART = [
  //  z       r       relief
  [ -0.20,  6.007,  0.00 ],   // head face, 0.2 mm axial clearance
  [  3.40,  6.007,  0.00 ],   // straight rim bore (extractor groove relieved)
  [  3.40,  5.982,  0.00 ],   // case body, head end
  [ 49.00,  5.602,  0.00 ],   // case body, shoulder end
  [ 53.30,  4.317,  0.30 ],   // shoulder / neck junction
  [ 63.35,  4.317,  0.30 ],   // case mouth
  [ 63.35,  3.925,  0.50 ],   // bullet bearing surface
  // ... ogive points to [ 84.84, 0.300, 0.50 ]
];
```

The cavity is a solid of revolution built from the table with clearance added
radially:

```openscad
module cradle_solid() {
  pts = concat(
    [ [ 0, CART[0][0] ] ],
    [ for (p = CART) [ p[1] + clearance + p[2], p[0] ] ],
    [ [ 0, CART[len(CART) - 1][0] ] ]
  );
  rotate_extrude($fn = nest_fn) polygon(pts);
}
```

## Datum scheme

```mermaid
flowchart LR
    H["Case head<br/>z = 0"] -->|butts against| HS["Head stop wall<br/>AXIAL DATUM"]
    R["Rim O12.014"] -->|rides| RB["Rim bore<br/>straight, z = -0.2 .. 3.4"]
    B["Case body cone"] -->|seats in| BC["Body cradle<br/>z = 3.4 .. 49"]
    RB --> LOC["Located on two datums,<br/>as a chamber does"]
    BC --> LOC
```

The cartridge is located by the **rim bore and the body cone only**. Everything
past the shoulder carries extra relief and is not a locating surface.

## Deliberate departures from the real shape

These are design decisions, not omissions. Do not "fix" them:

- **The extractor groove is not reproduced.** The rim rides a plain straight bore
  from z = -0.20 to 3.40 and the groove is left in free air. Reproducing a
  0.8 mm wide groove invites a printed bump inside it, which would rock the
  cartridge and destroy the levelness the whole design is built on.
- **Extra relief past the shoulder** (0.30 mm at the neck, 0.50 mm on the
  bullet). This lets a fire-formed case, or a case with no bullet seated at all,
  still drop in. A blank-fired case simply sits in the case portion of the cradle
  with the bullet portion empty.
- **0.2 mm axial clearance at the head face** so the round drops in without
  binding, then pushes back against the head stop.

## Contracts

- **Uniform radial offset means uniform contact.** Because every point is offset
  by the same `clearance`, the cartridge settles by exactly `clearance` and
  contacts along its whole length at once. This is what makes the seated height
  a fixed, repeatable offset rather than a rattle.
- `clearance = 0.35` suits factory brass; **0.50** for fire-formed cases.
- Changing `CART` invalidates `body_k` and therefore the tilt. See
  [levelling-tilt.md](levelling-tilt.md).

## Lessons learned

The supplied mesh is coarse in the cylindrical region - vertex rings only every
~9 mm - so naive vertex sampling in narrow bands returns empty sets. Evaluate at
the actual ring positions instead; the surface between them is a straight cone,
so ring values bound the whole span.

## Related

- [levelling-tilt.md](levelling-tilt.md)
- [../process/verification.md](../process/verification.md)
- [../publishing/licensing.md](../publishing/licensing.md) - the mesh is CC BY

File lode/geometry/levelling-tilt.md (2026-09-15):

# The Levelling Tilt

The central idea of the fixture. A .30-06 case body is tapered, so a cartridge
lying in a plain cradle presents a marking surface that is **not level**, which
walks the work in and out of focus along the length of the text.

## The problem

```mermaid
flowchart TB
    subgraph PLAIN["Plain cradle - axis horizontal"]
        P["apex drops 0.380 mm<br/>over the 45.6 mm body"]
    end
    subgraph TILTED["Cradle tilted nose-up by atan(k)"]
        T["apex constant<br/>0.0061 mm non-flatness"]
    end
    PLAIN -->|"tilt axis by body half-taper"| TILTED
```

Body radius falls from 5.982 at z=3.40 to 5.602 at z=49.00.

## The derivation

Let `k` be the body half-taper slope and `a` the nose-up tilt of the axis. With
the axis height rising as `h(x) = h0 + x * tan(a)` and the radius falling as
`r(x) = r0 - k * x`, the apex line is:

```
top(x) = h(x) + r(x)
       = h0 + x*tan(a) + r0 - k*x
```

The `x` terms cancel when `tan(a) = k`, leaving `top(x) = h0 + r0`, a constant.

```openscad
// Body half-taper, and the nose-up tilt that cancels it.
body_k    = (5.982 - 5.602) / (49.00 - 3.40);   // 0.0083333 mm/mm
tilt      = atan(body_k);                       // 0.477454 deg

// Height of the levelled engraving surface above the carrier top face,
// with the cartridge settled onto the cradle.
mark_rise = 5.982 + body_k * 3.40 - clearance;  // 5.66033
```

Applied as a single rotation when the nest is placed:

```openscad
module nest_cavity() {
  translate([head_margin, 0, carrier_h])
    rotate([0, 90 - tilt, 0])
      nest_cavity_local();
}
```

## Verified result

Measured against the real mesh at its true vertex rings, not against the
transcribed profile:

| cartridge z | true r | apex height |
|---|---|---|
| 3.160 | 5.9821 | 5.6585 |
| 12.426 | 5.9062 | 5.6597 |
| 21.692 | 5.8302 | 5.6609 |
| 30.958 | 5.7542 | 5.6621 |
| 40.224 | 5.6782 | 5.6634 |
| 49.490 | 5.6022 | 5.6646 |

**Non-flatness 0.0061 mm**, against 0.380 mm untilted. Six microns is an order of
magnitude below what an FDM printer can hold and irrelevant beside the depth of
field of a CO2 lens.

## Contracts

- `tilt` **must** equal `atan(body_k)`. It is derived, never typed in. If `CART`
  changes, `body_k` changes and the tilt follows automatically - but the result
  must be re-verified.
- The head-end axis sits exactly at the carrier top face, and rises from there.
  This is load-bearing for [lift-out-invariant.md](lift-out-invariant.md).
- Resulting heights: marking surface **5.660 mm** above the carrier top face,
  **18.660 mm** above the laser bed.

## Lessons learned

The tilt is small enough (0.477 deg) to look like a rounding error in the source.
It is not; it is the whole point of the fixture. Anyone "cleaning up" the model
by zeroing it reintroduces a 0.380 mm focus walk.

## Related

- [cartridge-profile.md](cartridge-profile.md) - where `body_k` comes from
- [lift-out-invariant.md](lift-out-invariant.md) - the other half of the tilt
- [../process/laser-setup-and-batch.md](../process/laser-setup-and-batch.md)

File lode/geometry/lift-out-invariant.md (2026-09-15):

# The Lift-Out Invariant

A cartridge must lift straight up out of its cradle. This is both a usability
requirement (150 pieces get loaded and flipped by hand) and the user's original
constraint that a round nest "no more than half" into the fixture.

## The rule

> The cradle axis must sit **at or above the carrier top face at every station**.

The carrier's top face is the parting plane, and the cradle is whatever part of
the solid of revolution falls below it.

```mermaid
flowchart TB
    A["Axis at or ABOVE top face"] --> B["Widest point of every<br/>horizontal section is at the top"]
    B --> C["Section width increases<br/>monotonically with height"]
    C --> D["No undercut -> lifts straight out"]
    E["Axis BELOW top face"] --> F["Widest point is buried<br/>below the opening"]
    F --> G["Undercut -> trapped round"]
```

## Why it holds

The nest is placed with its axis exactly at the carrier top face at the head, and
the nose-up `tilt` only ever raises it:

```openscad
// axis height along the cartridge
h(x) = carrier_h + x * tan(tilt)     // x >= 0  =>  h(x) >= carrier_h
```

Because every cross-section of a solid of revolution is a circle centred on that
axis, and the axis never dips below the cut plane, each section's width grows
monotonically upward. No undercut anywhere.

Capture depth along the body stays deep enough to cradle the round securely:

| station | axis above top face | capture depth |
|---|---|---|
| x = 3.4 (body start) | 0.028 | 5.95 |
| x = 49 (shoulder) | 0.408 | 5.19 |

So the round is held through most of its radius, yet never past its centreline.

## Side effects worth knowing

- **Self-centring.** A circular section in a circular cradle settles to the
  bottom of the arc, so the round centres itself laterally with no adjustment.
- **Free rotation.** The round can spin about its own axis in the cradle, which
  is exactly what the 180 degree flip needs.
- **Printability for free.** The same monotonic-widening property means the
  cavity has no downward-facing surfaces, so the carrier prints with **no
  supports**, cradles facing up.

## Contracts

- Never lower the nest axis below `carrier_h`, and never add a negative tilt.
- Any feature added inside the cavity must also respect the rule. The tip channel
  and eject slot do, because both are cut downward from the axis.

## Lessons learned

The cavity is built in cartridge-local coordinates and then rotated by
`[0, 90 - tilt, 0]`. After that rotation **local +X is "down" in carrier space**,
not local Y. Getting this wrong once produced an eject slot that ran 21 mm
sideways into neighbouring nests while reaching only 5.5 mm down. The model still
rendered as a valid manifold, so it passed every automated check and was only
caught by looking at a render. Axis-mapping bugs in rotated frames are invisible
to manifold checks - render and look.

```openscad
// Local +X becomes "down" in carrier space once the nest is rotated, so the
// slot is driven along +X to break through the carrier floor.
translate([-eject_w / 2, -eject_w / 2, eject_from])
  cube([eject_w / 2 + carrier_h + 1, eject_w, eject_to - eject_from]);
```

## Related

- [levelling-tilt.md](levelling-tilt.md) - supplies the tilt this depends on
- [../fixture/carrier.md](../fixture/carrier.md)
- [../process/printing-and-machines.md](../process/printing-and-machines.md)

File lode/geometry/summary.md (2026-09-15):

# Geometry

Everything about the shape of the cavity a cartridge sits in, and the two
invariants that make the fixture work.

```mermaid
flowchart TD
    STL["Cartridge.stl<br/>(CC BY, is-serp)"] -->|measured| CART["CART profile table<br/>z, radius, relief"]
    SAAMI["SAAMI .30-06 spec"] -->|cross-check| CART
    CART --> K["body_k = taper slope<br/>0.0083333"]
    K --> TILT["tilt = atan(body_k)<br/>0.477454 deg"]
    CART --> CRADLE["cradle_solid()<br/>rotate_extrude"]
    TILT --> NEST["nest_cavity()<br/>rotate 90 - tilt"]
    CRADLE --> NEST
    NEST --> I1["INVARIANT: apex line level"]
    NEST --> I2["INVARIANT: no undercut"]
```

## Files

- [cartridge-profile.md](cartridge-profile.md) - the `CART` table, what is
  reproduced, what is deliberately relieved, and why.
- [levelling-tilt.md](levelling-tilt.md) - the nose-up tilt that cancels the
  body taper. The central idea of the whole fixture.
- [lift-out-invariant.md](lift-out-invariant.md) - why the cradle axis must never
  sit below the carrier top face.

## The two invariants

Both are consequences of the same tilt, and both must be rechecked together if
the profile or tilt ever changes:

1. **The apex line is level.** Holds to 0.0061 mm across the case body.
2. **Nothing is captured past its own centreline.** Every round lifts straight
   out; this is also the user's original "no more than half" requirement.

## Related

- [../fixture/carrier.md](../fixture/carrier.md) - where the cavity is placed
- [../process/verification.md](../process/verification.md) - how fit is proven

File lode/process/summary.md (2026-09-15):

# Process

Getting from the model to marked cartridges.

```mermaid
flowchart LR
    SCAD["bullet-jig.scad"] -->|openscad -D| STL["stl/*.stl"]
    STL --> PRINT["Print<br/>Prusa XL"]
    PRINT --> FA["First-article check"]
    FA -->|pass| SETUP["Square, tape, focus,<br/>measure real pitch"]
    FA -->|fail| PRINT
    SETUP --> RUN["Batch run<br/>side 1, flip, side 2"]
    SCAD --> VER["verify.scad<br/>must render empty"]
```

## Files

- [printing-and-machines.md](printing-and-machines.md) - machine budgets, print
  settings, regenerating STLs
- [laser-setup-and-batch.md](laser-setup-and-batch.md) - setting up the P2 and
  running a batch
- [verification.md](verification.md) - the automated fit test and the
  first-article check

## Related

- [../fixture/registration.md](../fixture/registration.md)

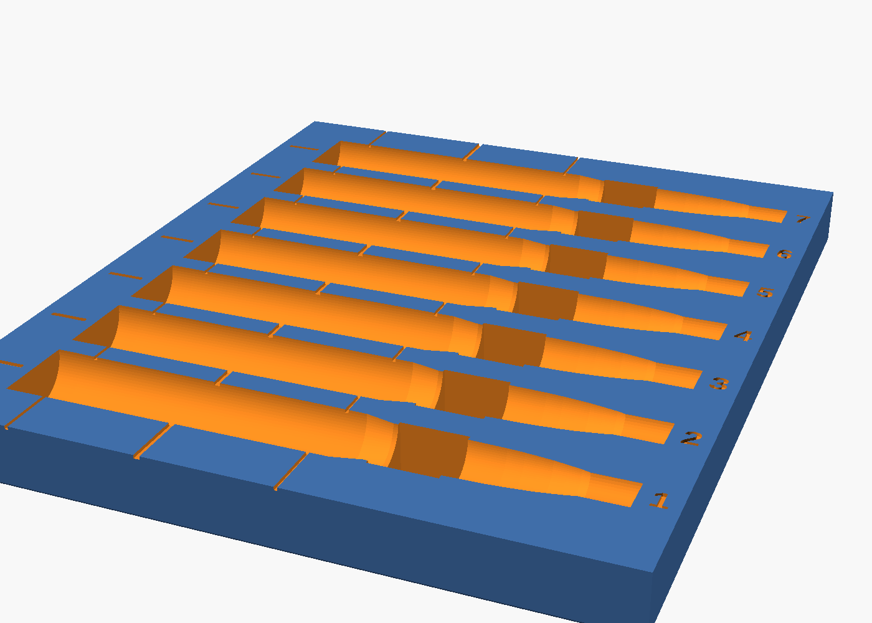
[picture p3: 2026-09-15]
docs/carrier.png

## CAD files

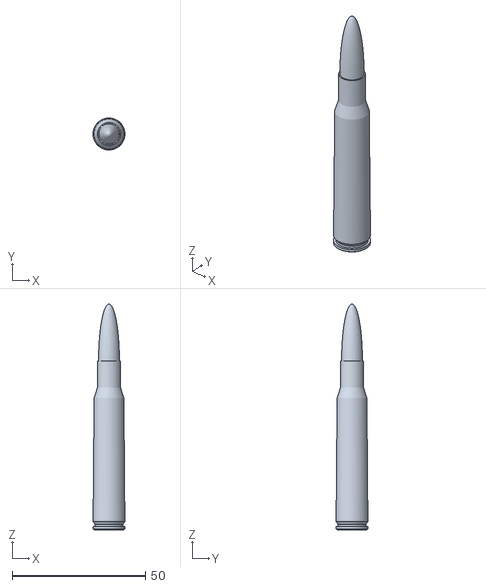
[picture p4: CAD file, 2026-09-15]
Cartridge.stl
12.0 x 12.0 x 84.8

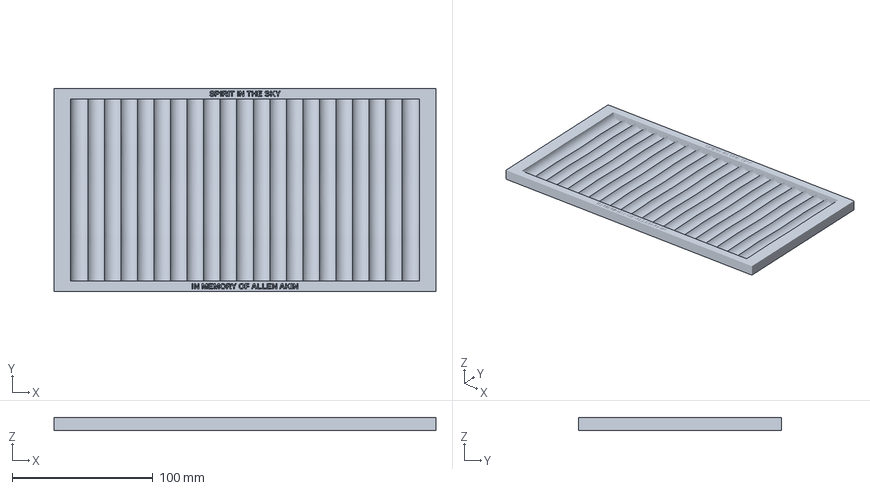
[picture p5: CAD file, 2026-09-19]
stl/display-plate-top.3mf
271.0 x 144.1 x 9.01 mm

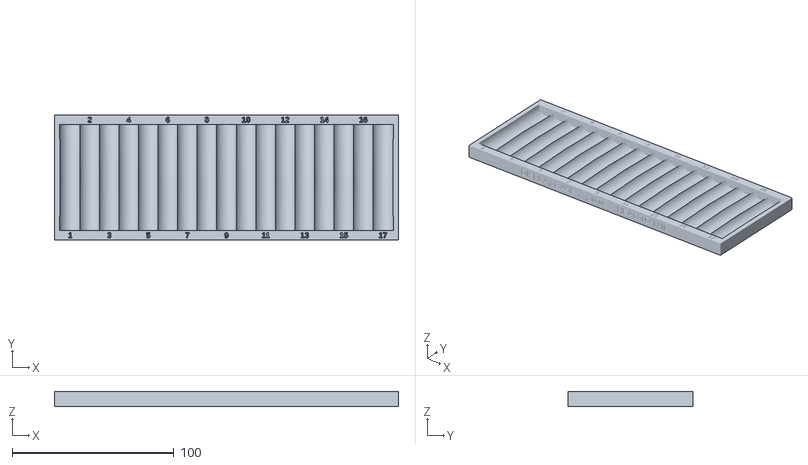
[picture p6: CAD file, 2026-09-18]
stl/display-plate-17up.stl
212.9 x 77.6 x 9.01

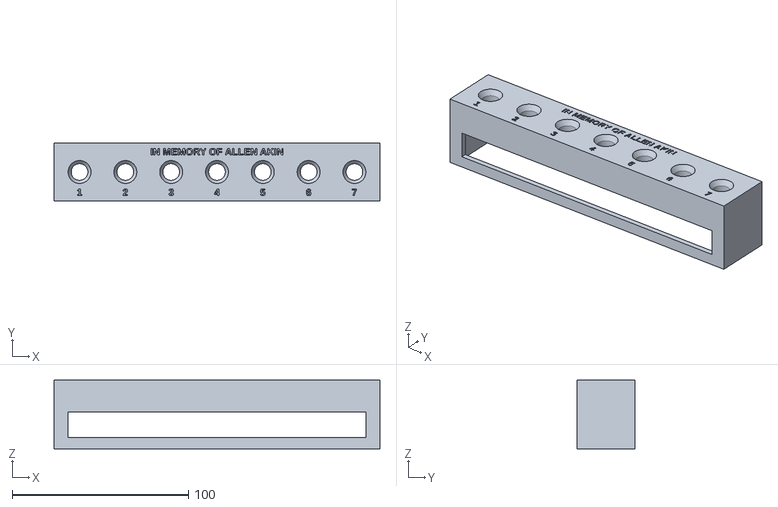
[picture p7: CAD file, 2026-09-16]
stl/spray-stand-7nest.stl
185.0 x 33.0 x 38.9

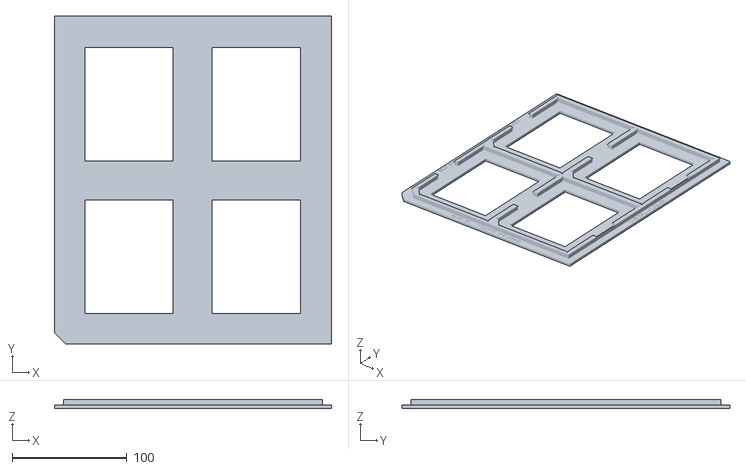
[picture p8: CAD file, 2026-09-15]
stl/base-28up.stl
241.6 x 285.6 x 8.00

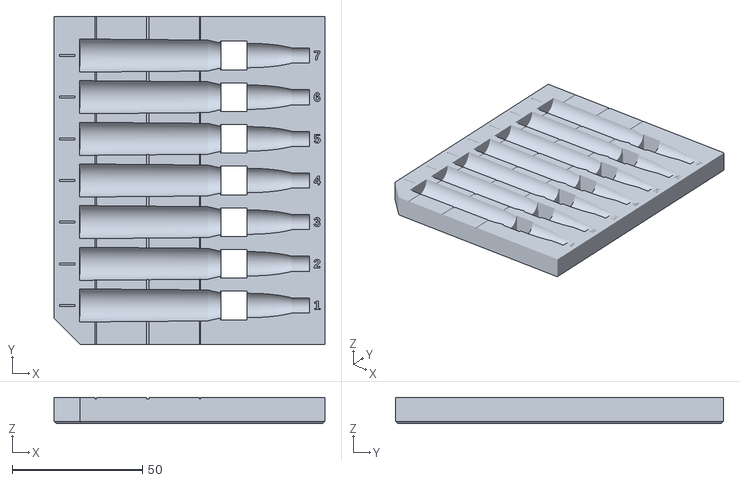
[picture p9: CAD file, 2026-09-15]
stl/carrier-7nest.stl
104.0 x 126.0 x 10.0

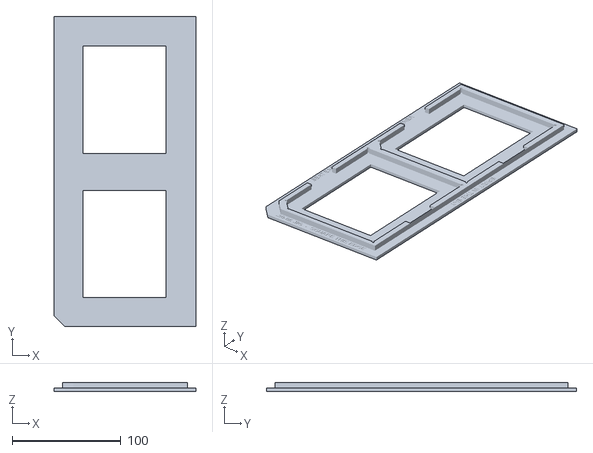
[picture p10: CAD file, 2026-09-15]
stl/base-14up.stl
130.8 x 285.6 x 8.00

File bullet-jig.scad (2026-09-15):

// =============================================================================
//  .30-06 Cartridge Laser-Marking Jig
// =============================================================================
//  A two-part fixture for laser-marking .30-06 Springfield cartridges:
//
//    BASE    - taped and squared to the laser bed once, then left alone.
//    CARRIER - drops into the base, holds N cartridges, lifts out for reloading.
//
//  The cradle is a true negative of the measured SAAMI .30-06 profile, tilted
//  nose-up by the body half-taper so the engraved surface is LEVEL end to end.
//
//  Machines this was dimensioned for:
//    Laser   xTool P2 / P2S  (600 x 308 mm bed)  - cartridges lie along X (600)
//    Printer Prusa XL        (360 x 360 x 360)
//
//  Units: millimetres.
//
//  Written for the cartridges marked in memory of Allen Akin, d. September 8, 2026.
//
//  The cradle profile was taken from "Cartridge.stl", derived from
//  ".30-06 Springfield" by is-serp, https://www.printables.com/model/101907
//  licensed CC BY 4.0. Checked against SAAMI .30-06 Springfield dimensions.
//
//  This jig: CC BY 4.0. See LICENSE and the Credits section of README.md.
// =============================================================================

/* [What to render] */
// carrier = the removable nest block, base = the taped-down tray
part = "both";  // [carrier, base, both, demo, none]

/* [Cartridge fit] */
// Radial gap between cartridge and cradle. 0.35 for new/factory brass,
// raise to 0.50 if you are marking fire-formed (once-fired) cases.
clearance = 0.35;

/* [Nest layout] */
// Cartridges per carrier
nest_count  = 7;
// Centre-to-centre spacing of the cradles
nest_pitch  = 16;
// Solid material outboard of the first and last cradle
side_margin = 7;
// Solid material behind the case head (this face is the axial datum)
head_margin = 10;
// Overall carrier length along the cartridge axis
carrier_len = 104;
// Carrier thickness. Top face sits on the cartridge centreline.
carrier_h   = 10;

/* [Base tray] */
// Carrier pockets across the bed. 1 x 2 = 14 up; 2 x 2 = 28 up (still fits both machines).
pockets_x = 1;
pockets_y = 2;
// Drop-in gap around the carrier, per side
pocket_clr  = 0.4;
// How deep the carrier sinks into the base
pocket_depth = 5;
// Base floor thickness
base_floor  = 3;
// Wall thickness around the pockets
base_wall   = 5;
// Wall between adjacent pockets
divider     = 6;
// Flat tape-down / squaring border outside the walls
flange      = 8;
// 45 degree keyed corner. Breaks all symmetry, so a carrier only seats one way.
key_chamfer = 10;

/* [Markings] */
// Depth of engraved reference lines and numbers
mark_depth  = 0.5;
// Engraving window measured from the case head, along the cartridge
window_from = 6;
window_to   = 46;

/* [Dedication] */
// Engraved into the free flanges of the base. Set either to "" to omit.
// Kept as parameters so anyone reusing this jig can put their own words here.
dedication      = "IN MEMORY OF ALLEN AKIN";
dedication_edge = "SPIRIT IN THE SKY";

/* [Hidden] */
$fn = 48;
nest_fn = 96;
eps = 0.01;

// -----------------------------------------------------------------------------
//  Cartridge profile
// -----------------------------------------------------------------------------
//  [ axial position from case head, radius, extra local relief ]
//
//  Taken from the supplied Cartridge.stl and cross-checked against SAAMI:
//    rim  O12.014   body O11.964 -> O11.204   neck O8.634   COAL 84.84
//
//  The extractor groove is deliberately NOT reproduced. A printed bump in a
//  0.8 mm wide groove would rock the cartridge; instead the rim rides a plain
//  straight bore and the groove is simply left in free air.
//
//  Extra relief is added past the shoulder so that a fire-formed case, or one
//  with no bullet seated at all, still drops in. The cartridge is located by
//  the rim bore and the body cone only - the same two datums a chamber uses.

CART = [
  //  z       r       relief
  [ -0.20,  6.007,  0.00 ],   // head face, 0.2 mm axial clearance
  [  3.40,  6.007,  0.00 ],   // straight rim bore (extractor groove relieved)
  [  3.40,  5.982,  0.00 ],   // case body, head end
  [ 49.00,  5.602,  0.00 ],   // case body, shoulder end
  [ 53.30,  4.317,  0.30 ],   // shoulder / neck junction
  [ 63.35,  4.317,  0.30 ],   // case mouth
  [ 63.35,  3.925,  0.50 ],   // bullet bearing surface
  [ 69.50,  3.753,  0.50 ],
  [ 72.00,  3.584,  0.50 ],
  [ 74.00,  3.387,  0.50 ],
  [ 76.00,  3.175,  0.50 ],
  [ 78.00,  2.834,  0.50 ],
  [ 80.00,  2.464,  0.50 ],
  [ 82.00,  1.948,  0.50 ],
  [ 83.00,  1.567,  0.50 ],
  [ 84.00,  1.009,  0.50 ],
  [ 84.84,  0.300,  0.50 ],
];

// Body half-taper, and the nose-up tilt that cancels it.
body_k    = (5.982 - 5.602) / (49.00 - 3.40);   // 0.0083333 mm/mm
tilt      = atan(body_k);                       // 0.47746 deg

// Height of the levelled engraving surface above the carrier top face,
// with the cartridge settled onto the cradle.
mark_rise = 5.982 + body_k * 3.40 - clearance;

// Relief channel past the bullet ogive, so an over-long round cannot bind and
// so there is somewhere to get a fingertip in from the nose end.
tip_r     = 3.0;
tip_from  = 78;
tip_to    = 88;   // carrier X 98, leaving a solid band out to 104

// Through-slot at the case neck: push a cartridge up from underneath to eject.
eject_from = 54;
eject_to   = 64;
eject_w    = 11;

// -----------------------------------------------------------------------------
//  Helpers
// -----------------------------------------------------------------------------

// Rectangle with the corner at the origin cut off at 45 degrees, optionally
// offset outward by o. Offsetting a 45 degree chamfer slides its ends by
// o*(sqrt(2)-1) along the adjacent edges.
function keyed_rect(sx, sy, c, o = 0) = [
  [ c - 0.41421 * o, -o ],
  [ sx + o,          -o ],
  [ sx + o,          sy + o ],
  [ -o,              sy + o ],
  [ -o,              c - 0.41421 * o ],
];

// Solid of revolution matching the cradle cavity (cartridge + clearance).
module cradle_solid() {
  pts = concat(
    [ [ 0, CART[0][0] ] ],
    [ for (p = CART) [ p[1] + clearance + p[2], p[0] ] ],
    [ [ 0, CART[len(CART) - 1][0] ] ]
  );
  rotate_extrude($fn = nest_fn) polygon(pts);
}

// Everything cut away for one cartridge, expressed in cartridge coordinates
// (+Z along the cartridge axis, origin at the case head) before tilting.
module nest_cavity_local() {
  cradle_solid();
  translate([0, 0, tip_from]) cylinder(h = tip_to - tip_from, r = tip_r);
  // Local +X becomes "down" in carrier space once the nest is rotated, so the
  // slot is driven along +X to break through the carrier floor.
  translate([-eject_w / 2, -eject_w / 2, eject_from])
    cube([eject_w / 2 + carrier_h + 1, eject_w, eject_to - eject_from]);
}

// One nest placed in carrier coordinates: axis along +X, case head at
// head_margin, axis at the carrier top face and rising nose-up by `tilt`.
// Keeping the axis at or above the top face everywhere is what guarantees the
// cartridge is never captured past its own centreline, so it lifts straight out.
module nest_cavity() {
  translate([head_margin, 0, carrier_h])
    rotate([0, 90 - tilt, 0])
      nest_cavity_local();
}

function nest_y(i) = side_margin + nest_pitch / 2 + i * nest_pitch;

// -----------------------------------------------------------------------------
//  Carrier
// -----------------------------------------------------------------------------

carrier_y = nest_count * nest_pitch + 2 * side_margin;

module carrier() {
  P = keyed_rect(carrier_len, carrier_y, key_chamfer);

  difference() {
    union() {
      // 0.8 mm chamfer on the bottom edge so elephant's foot cannot stop the
      // carrier from seating flat in the pocket.
      hull() {
        linear_extrude(eps) offset(delta = -0.8) polygon(P);
        translate([0, 0, 0.8]) linear_extrude(eps) polygon(P);
      }
      translate([0, 0, 0.8]) linear_extrude(carrier_h - 0.8) polygon(P);
    }

    for (i = [0 : nest_count - 1])
      translate([0, nest_y(i), 0]) nest_cavity();

    carrier_markings();
  }
}

module carrier_markings() {
  z = carrier_h - mark_depth;

  // Engraving window: two fine lines at the ends of the usable case body and a
  // heavier one on its centre. They cross the cradles, so they read as dashes
  // between nests - line up the laser to these rather than to nominal numbers,
  // which is what makes print shrinkage irrelevant.
  for (m = [[window_from, 0.5], [window_to, 0.5],
            [(window_from + window_to) / 2, 0.9]])
    translate([head_margin + m[0] - m[1] / 2, -eps, z])
      cube([m[1], carrier_y + 2 * eps, mark_depth + eps]);

  for (i = [0 : nest_count - 1]) {
    // Centreline tick on the solid band behind the case head.
    translate([2, nest_y(i) - 0.4, z]) cube([6, 0.8, mark_depth + eps]);
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

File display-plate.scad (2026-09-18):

// =============================================================================
//  .30-06 Casing Display / Organizer Plate
// =============================================================================
//  A loose organizer, not a precision fixture. Fired EMPTY CASINGS (no bullet,
//  ~63 mm to the mouth) are dropped on their sides into a scalloped plate. Each
//  cradle holds one casing; a row of cradles seats a base row, and further
//  casings nest in the valleys between them so the pile self-stacks into an open
//  pyramid - cannonball fashion.
//
//  Two footprints, selected by `variant`:
//    * "drawer" - fills a mini tool-chest DRAWER (8.5" wide), a single row -> 17.
//    * "top"    - sits on the tool-chest TOP (10.75" x 6.75"), two rows -> 22 each.
//  Both share every cradle dimension; they differ only in outline and row count.
//
//  These are party favours: every casing must DROP IN AND LIFT OUT FREELY, so
//  the fit is deliberately loose - the opposite instinct from the jig:
//    * The cradle wraps only the LOWER HALF of the casing (sink = 0), so a casing
//      drops straight down instead of being angled past a lip.
//    * Generous radial and axial clearance, sized to swallow print shrink. A test
//      print measured the channel ~1 mm short of nominal (~1.2 % on that printer);
//      axial_clr is set well above that. If yours binds, raise round_clr /
//      axial_clr - these are slop knobs, not a tight fit.
//
//  What keeps a row uniform: casings are laid HEAD-TO-TAIL (alternating), so each
//  adjacent pair meets fat-body-to-fat-body, the pitch is the body diameter, and
//  the valleys run level for the next layer to nest. Each cradle is the casing's
//  own profile of revolution, unioned with its mirror, so it seats level whichever
//  way it points.
//
//  Units: millimetres. Prints flat, base down, no supports (grooves open up).
//
//  Casing profile shared with bullet-jig.scad (CART, truncated at the mouth).
//
//  Written for the cartridges marked in memory of Allen Akin, d. September 8, 2026.
//  This plate: CC BY 4.0. See LICENSE and the Credits section of README.md.
// =============================================================================

/* [What to render] */
// plate = the part to print, demo = plate with a base row + one nested layer
part = "plate";  // [plate, demo]
// drawer = 8.5" drawer, one row.  top = 10.75 x 6.75" chest top, two rows.
variant = "drawer";  // [drawer, top]

/* [Drawer footprint] */
// Interior width of the tool-chest drawer the plate drops into. 8.5" = 215.9.
drawer_w = 215.9;
// Gap left on each side so the plate slides in and out without binding.
fit_clr  = 1.5;

/* [Chest-top footprint] */
// The tool-chest top opening. 10 3/4" wide x 5 3/4" front-to-back (measured).
top_w = 273.05;
top_d = 146.05;
// How far the plate is held back from each top edge. Small, so the plate nearly
// fills the well and cannot slide far - the depth is tight, so slide eats lip
// clearance directly.
pullback = 1.0;
// Gap between the casing ends of the two rows where they meet near the centre.
// Kept small: on the short top the rows must nearly touch to clear the lip.
row_gap  = 0.5;
// The lid closes over an inward LIP this wide on every edge. Any casing under it
// stops the lid closing, so the casings are held this far (plus lip_clr) back
// from the lid opening - even though the plate itself still fills the well.
lid_lip = 8.0;
// Extra safety inside the lip, to swallow the little the plate can slide in the
// well. This much clear space is left past the lip on every edge.
lip_clr = 4.0;
// Rows laid front-to-back on the top.
top_rows = 2;

/* [Casing fit - the slop knobs] */
// Measured length of a real casing (head face to mouth), for the fit report.
casing_len = 63.25;
// Radial gap between the brass and the cradle wall. Loose on purpose so a casing
// drops in and lifts out; raise it if your printer runs tight.
round_clr  = 0.50;
// Extra channel length beyond the casing profile (split fore and aft). Sized to
// clear the casing even after the printer shrinks the channel a millimetre or so.
axial_clr  = 2.00;
// How far below the plate top the casing AXIS sits. 0 = the cradle wraps exactly
// the lower half, so casings drop straight in. Positive grips past the equator
// (more retention, harder to remove) - keep at 0 for party favours.
sink       = 0.0;

/* [Plate body] */
// Solid plastic under the deepest point of a cradle.
floor      = 2.5;
// Flat solid band at the ends of a row, for the head marks and so casing ends do
// not overhang the plate edge.
end_margin = 6;
// Minimum solid wall from the outermost cradle to the side edge of the plate.
edge_wall  = 2.5;

/* [Markings] */
// Depth of engraved numbers, title and dedication.
mark_depth = 0.5;
// Casing number engraved at the end where that casing's HEAD goes. The numbers
// zig back and forth so following them lays the casings head-to-tail without
// thinking. Set false for a plain plate.
number_nests = true;

/* [Dedication] */
// Engraved into the plate. Set to "" to omit. Parametric so anyone reusing this
// can put their own words here. His cartridges carried his name on one side and
// the song on the other; on the top variant both are engraved down the centre,
// between the two rows. On the drawer variant, `title` runs on the front face and
// `dedication` on the back.
title           = "DISPLAY BASE  -  .30-06  -  HEAD TO TAIL";
dedication      = "IN MEMORY OF ALLEN AKIN";
dedication_edge = "SPIRIT IN THE SKY";

/* [Hidden] */
$fn = 64;
eps = 0.01;

is_top = (variant == "top");

// Air gap between adjacent casings in a row, on top of the touching pitch. The
// drawer wants finger room; the top packs tight to make the row count.
stack_gap = is_top ? 0.25 : 0.60;

// -----------------------------------------------------------------------------
//  Casing geometry (from bullet-jig.scad CART, truncated at the mouth: no bullet)
// -----------------------------------------------------------------------------
//  [ axial position from case head, radius ].  A fired empty casing.

CASE = [
  //  z       r
  [ -0.20,  6.007 ],   // rim / head face   (O12.014, the widest point)
  [  3.40,  6.007 ],   // straight rim bore
  [  3.40,  5.982 ],   // case body, head end
  [ 49.00,  5.602 ],   // case body, shoulder end
  [ 53.30,  4.317 ],   // shoulder / neck junction
  [ 63.35,  4.317 ],   // case mouth        (open end, no bullet)
];

case_z0    = CASE[0][0];
case_z1    = CASE[len(CASE) - 1][0];
profile_len = case_z1 - case_z0;           // 63.55, nominal casing envelope
channel_len = profile_len + axial_clr;     // the actual cut length, with slop
case_mid   = (case_z0 + case_z1) / 2;      // 31.575, the mirror axis
rim_r      = CASE[0][1];                    // 6.007, sets cradle depth & side wall
mouth_r    = CASE[len(CASE) - 1][1];        // 4.317

// Body taper and the radius at the casing centre - the pair of these on two
// alternating neighbours is what they touch on, so it sets the minimum pitch.
body_k    = (5.982 - 5.602) / (49.00 - 3.40);        // 0.0083333 mm/mm
r_centre  = 5.982 - body_k * (case_mid - 3.40);      // ~5.7472
contact_d = 2 * r_centre;                            // ~11.4944, cheek to cheek

// -----------------------------------------------------------------------------
//  Derived layout
// -----------------------------------------------------------------------------

rows      = is_top ? top_rows : 1;
plate_w   = is_top ? top_w - 2 * pullback : drawer_w - 2 * fit_clr;
plate_depth = is_top ? top_d - 2 * pullback     // fill the chest top
                     : channel_len + 2 * end_margin;   // snug to one row

pitch     = contact_d + stack_gap;         // centre-to-centre within a row

// A cradle's mouth at the top surface is widest at the rim band; its half-width
// there sets how close the outer cradle can come to the plate edge.
mouth_hw  = sqrt(pow(rim_r + round_clr, 2) - sink * sink);
first_cx  = edge_wall + mouth_hw;          // centre of the outermost cradle

// On the top the casings must clear the lid lip on every edge; on the drawer the
// only limit is the side wall. keepout is the clear zone the casings live in,
// measured from the lid opening edge, and the field is centred on the lid.
keepout   = lid_lip + lip_clr;

// Row count across the width, centred on the lid.
count     = is_top
  ? floor((top_w - 2 * keepout - 2 * mouth_hw) / pitch) + 1
  : floor((plate_w - 2 * first_cx) / pitch) + 1;
row_span  = (count - 1) * pitch;
margin_x  = (plate_w - row_span) / 2;      // outer cradle sits >= keepout in
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

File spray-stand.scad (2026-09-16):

// =============================================================================
//  .30-06 Cartridge Clear-Coat Spray Stand
// =============================================================================
//  A companion to the laser-marking jig. After a batch is marked, the rounds
//  are stood NOSE-DOWN in this stand and clear-coated (rattle-can topcoat over
//  the CerMark). Standing vertical means one rotating pass coats the whole
//  circumference, so BOTH marked sides are covered without a flip-and-redry.
//
//  Each round drops NOSE-FIRST into a bore. The slender bullet and neck lead in;
//  the SHOULDER (the wide-to-narrow cone at z 49-53 from the head, which is also
//  the .30-06 headspace datum) catches on the bore lip as a self-centring axial
//  stop, while the neck stays captured in the bore below and cannot cock over.
//  The head and the whole marking window stand straight up, in free air.
//
//  Nose-down, not nose-up, because a round balanced head-down on its rim is a
//  tall inverted pendulum and tips at a touch. Hanging by the shoulder with the
//  neck guided in a bore is stable and self-righting.
//
//  Units: millimetres.  Prints flat, base down, no supports.
//
//  Cartridge dimensions shared with bullet-jig.scad (the CART profile).
//
//  Written for the cartridges marked in memory of Allen Akin, d. September 8, 2026.
//  This stand: CC BY 4.0. See LICENSE and the Credits section of README.md.
// =============================================================================

/* [What to render] */
// stand = the part to print, demo = stand with rounds stood in it
part = "stand";  // [stand, demo]

/* [Nest fit] */
// Radial gap between the case neck and the guide bore. Smaller = less wobble,
// larger = drops in more freely (and tolerates overspray on the neck).
neck_clr  = 0.4;
// Countersink funnel at the bore mouth: leads the nose in and forms the seat lip.
cs_mouth_r = 6.5;
cs_depth   = 3;

/* [Nest layout] */
// One carrier's worth.
nest_count  = 7;
// Centre-to-centre spacing. Wide enough to spray around each and keep wet
// bodies from touching.
nest_pitch  = 26;
// Solid deck outboard of the end seats, along the row.
end_margin  = 8;
// Solid deck fore and aft of the seat centreline.
side_margin = 10;

/* [Deck and stand] */
// Deck plate thickness. The guide bore runs through it; deeper = longer neck
// guide (steadier) but more plastic.
deck_h   = 18;
// Skirt wall thickness.
skirt_w  = 3;
// Air gap left below the bullet tip, so it hangs clear of the bench. The skirt
// height is sized from this automatically.
tip_clr  = 3;

/* [Markings] */
// Depth of engraved title, numbers and dedication.
mark_depth = 0.5;

/* [Dedication] */
// Engraved into the deck. Set to "" to omit. Kept parametric so anyone reusing
// this stand can put their own words here.
title      = "CLEAR-COAT STAND  -  .30-06  -  NOSE DOWN";
dedication = "IN MEMORY OF ALLEN AKIN";

/* [Hidden] */
$fn = 64;
eps = 0.01;

// -----------------------------------------------------------------------------
//  Cartridge geometry the seat depends on (from bullet-jig.scad CART)
// -----------------------------------------------------------------------------
//  Shoulder cone: r 5.602 at z 49  ->  r 4.317 at z 53.3 (neck).
//  Neck r 4.317 (O8.634).  Tip at z 84.84.  Marking window ends at z 46.

neck_r  = 4.317;
sh_z1   = 49.00;  sh_r1 = 5.602;   // shoulder, body end
sh_z2   = 53.30;  sh_r2 = 4.317;   // shoulder, neck end
tip_zfh = 84.84;  window_to = 46;

// -----------------------------------------------------------------------------
//  Derived geometry
// -----------------------------------------------------------------------------

bore_r = neck_r + neck_clr;

// Axial position (from the case head) where the shoulder cone reaches bore_r and
// so catches on the bore lip. This is where the round seats.
seat_zfh = sh_z1 + (bore_r - sh_r1) * (sh_z2 - sh_z1) / (sh_r2 - sh_r1);

// Deck footprint. Seats in a single row along X, centred in Y.
deck_x = 2 * end_margin  + (nest_count - 1) * nest_pitch + 2 * cs_mouth_r;
deck_y = 2 * side_margin + 2 * cs_mouth_r;

// The seat lip sits cs_depth below the deck top. Everything from the seat down
// to the tip hangs below; size the skirt so the tip clears the bench.
tip_below_deckbot = (tip_zfh - seat_zfh) - (deck_h - cs_depth);
skirt_h  = tip_below_deckbot + tip_clr;

deck_top = skirt_h + deck_h;
seat_z   = deck_top - cs_depth;   // z of the seat lip

function nest_x(i) = end_margin + cs_mouth_r + i * nest_pitch;
seat_cy = side_margin + cs_mouth_r;

assert(bore_r < sh_r1, "bore must be narrower than the shoulder so the round seats");
assert(seat_zfh > window_to, "seat must sit past the marking window, or it shadows it");

// -----------------------------------------------------------------------------
//  One nest: the funnel + through bore the round drops into
// -----------------------------------------------------------------------------

module nest_cut() {
  // Lead-in funnel; its bottom edge is the self-centring seat lip.
  translate([0, 0, seat_z])
    cylinder(h = cs_depth + eps, r1 = bore_r, r2 = cs_mouth_r);
  // Guide bore for the neck, straight through the deck into the open skirt so
  // coating drains and the bullet hangs free.
  translate([0, 0, skirt_h - eps])
    cylinder(h = deck_h - cs_depth + 2 * eps, r = bore_r);
}

// -----------------------------------------------------------------------------
//  Stand
// -----------------------------------------------------------------------------

module skirt() {
  difference() {
    linear_extrude(skirt_h) square([deck_x, deck_y]);
    // Hollow it, leaving corners solid for rigidity.
    translate([skirt_w, skirt_w, -eps])
      linear_extrude(skirt_h + 2 * eps)
        square([deck_x - 2 * skirt_w, deck_y - 2 * skirt_w]);
    // Windows in the long sides: drainage, airflow, less plastic, finger access.
    for (y = [-eps, deck_y - skirt_w - eps])
      translate([end_margin, y, skirt_h * 0.3])
        cube([deck_x - 2 * end_margin, skirt_w + 2 * eps, skirt_h]);
  }
}
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

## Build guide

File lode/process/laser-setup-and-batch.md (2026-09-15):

# Laser Setup and Batch Running

## Setup, once

1. **Square the base** to the gantry on its long straight edge - the flange is
   engraved `SQUARE THIS EDGE`. Tape through the flange, outside the walls.
2. **Derive the real nest pitch** from the engraved ticks. This is the single
   most important step; see
   [../fixture/registration.md](../fixture/registration.md) and remember the
   span is across **6** gaps, not 7.
3. **Set focus from the marking surface**, nominally **18.660 mm** above the bed.
   Verify with calipers - an over-extruded cradle holds rounds slightly high,
   which is a fixed offset to measure, not a defect to fix.
4. **Centre the text** on the heavy engraved line, 36 mm from the carrier's
   head-end face. Usable window is 6-46 mm from the case head.

## Running a batch

```mermaid
sequenceDiagram
    participant O as Operator
    participant C as Carriers
    participant L as Laser
    O->>C: spray rounds OFF the jig, dry, then load
    O->>L: seat carriers into keyed corners
    L->>L: mark side 1, whole load
    O->>C: lift out, roll each round 180 by eye
    O->>L: reseat
    L->>L: mark side 2
    O->>C: swap in pre-loaded carriers
```

- **Spray off the jig.** Spraying loaded carriers coats the carriers, which then
  mark too. Rounds get sprayed on a rack and dried before loading.
- **Seat every round back against the head stop** and every carrier into its key
  corner.
- **Flip by eye** - roll until the first marking faces down. Accurate to a few
  degrees, which is invisible on a round cartridge.
- **Swap carriers** rather than unloading in place: load one set while another is
  under the laser. This is why several carriers are printed.

## Throughput

| Config | Per load | Loads for 150 |
|---|---|---|
| 14-up | 14 | ~11 per side |
| 28-up | 28 | ~6 per side |

## Safety

**Mark fired brass or inert dummy rounds only.** Live ammunition does not belong
under a laser; primers and propellant do not care that the beam is only meant to
reach the case wall. This is recorded in the repo README as well.

## Related

- [../fixture/registration.md](../fixture/registration.md)
- [verification.md](verification.md)

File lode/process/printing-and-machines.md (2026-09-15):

# Printing and Machines

## Target machines

| Machine | Envelope | Notes |
|---|---|---|
| xTool P2 / P2S | 600 x 308 mm bed, CO2 | The marking machine |
| Prusa XL | 360 x 360 x 360 | The printer |

**Orientation on the laser matters.** Cartridges lie along the P2's **600 mm
axis**, so text rasters along the fast axis; nests spread across the **308 mm**
axis. That makes 308 mm the binding constraint on how many nests fit, which is
why the base is long in the nest direction and short in the cartridge direction.

```mermaid
flowchart LR
    subgraph P2["xTool P2 bed"]
        direction TB
        X["X = 600 mm : cartridge axis, fast raster"]
        Y["Y = 308 mm : nest spread, BINDING CONSTRAINT"]
    end
```

Both bases fit both machines:

| Part | Size | vs XL 360x360 | vs P2 600x308 |
|---|---|---|---|
| carrier | 104 x 126 | fits | - |
| base-14up | 130.8 x 285.6 | fits | fits (285.6 < 308) |
| base-28up | 241.6 x 285.6 | fits | fits |

The 285.6 mm dimension is the tight one, with ~22 mm of margin on the P2. Raising
`nest_count` or `pockets_y` eats that margin; check it before changing either.

## Print settings

- PLA. Nothing here gets hot. PETG if scorching is a concern.
- 0.2 mm layers, 3 perimeters, 15-20% gyroid infill.
- **No supports** - the model is overhang-free by construction, see
  [../geometry/lift-out-invariant.md](../geometry/lift-out-invariant.md).
- Carriers print flat, cradles facing up.
- **Brim on the base.** Large thin plate, must sit dead flat.

## Regenerating STLs

```bash
openscad --export-format=binstl -D 'part="carrier"' \
  -o stl/carrier-7nest.stl bullet-jig.scad
openscad --export-format=binstl -D 'part="base"' \
  -o stl/base-14up.stl bullet-jig.scad
openscad --export-format=binstl -D 'part="base"' -D 'pockets_x=2' \
  -o stl/base-28up.stl bullet-jig.scad
```

`part` accepts `carrier`, `base`, `both`, `demo` (shows cartridges in place) and
`none`.

**Always pass `--export-format=binstl`.** OpenSCAD defaults to ASCII STL, which
is ~3.5x larger for identical geometry (2.5 MB vs 730 KB here).

Echoed dimensions on every render act as a cheap regression check:

```
carrier  104 x 126 x 10
base     130.8 x 285.6 x 8
tilt     0.477454 deg
mark surface above laser bed   18.6603
```

## Reprint economics

`clearance` and `pocket_clr` problems are **carrier-only reprints**. The base is
unaffected by either, so a fit failure never costs the long print. Worth
remembering when deciding what to print first.

## Related

- [verification.md](verification.md)
- [../fixture/summary.md](../fixture/summary.md)

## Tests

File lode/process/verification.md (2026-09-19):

# Verification

Two layers: an automated geometric test, and a first-article check on the printed
parts. They catch different classes of failure.

## Automated: verify.scad

`verify.scad` intersects the **real `Cartridge.stl` mesh** - not the transcribed
`CART` profile - against the cradle at its nominal, un-settled position. With
`clearance` of gap everywhere, the intersection must be empty.

```bash
openscad -o /tmp/v.stl verify.scad
# expect: "Current top level object is empty."
```

**Contract: any non-empty result means the cradle is transcribed too tight
somewhere.** Run this after touching `CART`, `clearance`, `tilt`, or any nest
geometry.

```mermaid
flowchart LR
    MESH["Real Cartridge.stl"] --> INT{"intersection"}
    CRADLE["Cradle at nominal position"] --> INT
    INT -->|empty| PASS["Fit proven"]
    INT -->|non-empty| FAIL["Cradle too tight"]
```

## What automated checks do NOT catch

A manifold render proves nothing about correctness. An eject slot that ran
sideways into neighbouring nests rendered as a perfectly valid manifold solid.
**Render an image and look at it** after any change to placement or orientation.

## First article, on the printed parts

Six checks on the printed parts, ordered so cheap ones gate expensive ones:

1. **Base flat?** On glass. If it rocks, stop - everything below is referenced
   off this plane.
2. **Carrier drops into the pocket?** 0.4 mm/side. Binding = shrinkage on the
   126 mm axis; raise `pocket_clr`, reprint carrier only.
3. **Cartridge seats against the head stop?** 0.35 mm radial. Binding = go to
   `clearance = 0.50`, reprint carrier only.
4. **Tick span.** Nominal 96.000 mm across 6 gaps. Divide by 6.
5. **Seated apex height 18.660 mm**, measured at **both ends** of the window.
   Two equal readings prove the tilt survived the print; a difference means the
   carrier is not flat, so return to step 1.
6. **Eject slot** clears - push a round up from under the base window.

If 1-3 pass, everything remaining is setup rather than geometry.

## Verified results held

| Claim | Value | How verified |
|---|---|---|
| Apex non-flatness | 0.0061 mm | real mesh, at true vertex rings |
| Cradle fit | no interference | `verify.scad` empty |
| Part sizes | 104x126x10, 130.8x285.6x8, 241.6x285.6x8 | STL bounding boxes |
| Manifold | all parts | OpenSCAD "Simple: yes" |

## Related

- [../geometry/levelling-tilt.md](../geometry/levelling-tilt.md)
- [../fixture/registration.md](../fixture/registration.md)

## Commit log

2026-09-15 Add parametric .30-06 cartridge laser-marking jig
    Two-part fixture for marking .30-06 cartridges in batches on two opposing
    sides, dimensioned for the xTool P2 (600x308 bed) and Prusa XL (360x360).
    The cradle is a true negative of the cartridge profile measured from
    Cartridge.stl and cross-checked against SAAMI .30-06 dimensions. Because the
    case body is tapered (O11.964 -> O11.204), a cartridge lying in a plain
    cradle has a top surface that drops 0.380 mm across the marking area. The
    cradle axis is therefore tilted nose-up by the body half-taper, 0.47746 deg,
    which cancels it: top(x) = h0 + x*tan(a) + r0 - k*x is constant when
    tan(a) = k. Measured against the real mesh, non-flatness is 0.0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
    [base-14up.stl, base-28up.stl, bullet-jig.scad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]
2026-09-15 Add first-article acceptance check
    Six checks to run on the first carrier and base off the printer, ordered so
    the cheap ones gate the expensive ones: base flatness, carrier fit, cartridge
    fit, tick span, seated apex height and levelness, eject slot.
    Records the measurement the setup actually depends on: the nest 1 to nest 7
    tick span is 96.000 mm across SIX gaps, not seven. Dividing by the nest count
    instead of the gap count puts the program 2.67 mm out per nest.
2026-09-15 Seed the lode
    Structured project memory under lode/, describing the current state of the
    fixture rather than the history of building it.
    geometry/ the CART profile and its deliberate relief, the nose-up tilt
    that cancels the body taper, and the lift-out invariant that
    keeps the cradle axis at or above the carrier top face
    fixture/ carrier and base tray, and the registration doctrine: align to
    engraved fiducials on the real printed part, never to nominal
    coordinates
    process/ machine budgets and print settings, laser setup and batch
    running, and the verify.scad contract
    publishing/ the two licences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
2026-09-16 Add nose-down clear-coat spray stand
    A companion fixture for clear-coating marked rounds. Each cartridge drops
    nose-first into a bore; the shoulder catches on the bore lip as a
    self-centring stop (at ~52 mm from the head, just past the 46 mm marking
    window) while the neck is guided in the bore below. The head and full
    marking window stand up in free air for a single rotating spray pass that
    covers both marked faces; the bullet tip hangs through the deck to drain.
    Nose-down rather than nose-up: a round balanced head-down on its rim ring is
    a tall inverted pendulum and tips at a touch.
    - spray-stand.scad + stl/spray-stand-7nest.stl (own parametric model)
    - README: Clear-coating section, STL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
    [spray-stand-7nest.stl, spray-stand.scad]
2026-09-18 Add casing display / organizer plate
    A stand-alone companion model, display-plate.scad, that drops into a mini
    tool-chest drawer (8.5" wide) and holds fired empty casings on their sides in a
    scalloped base row. The row seats in fixed cradles so further casings nest in the
    valleys and self-stack into an open pyramid. At defaults it holds 17 across the
    base row.
    Casings are laid head-to-tail: a tapered case body laid one way wedges the stack
    and collides at the rim, but alternating brings fat body against fat body, so the
    pitch is the body diameter and the valleys run level. Each cradle is the casing
    profile of revolution unioned with its mirror, so it seats level either way.
    Fit is delibera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
    [display-plate-17up.stl, display-plate.scad]
2026-09-18 Add chest-top display-plate variant (two rows of 22)
    Generalize display-plate.scad to be footprint- and row-driven with a `variant`
    switch. `drawer` (default) reproduces the shipped 8.5" single-row 17-up plate
    byte-for-byte in geometry; `top` sits on the tool-chest top (10.75 x 6.75",
    pulled back per edge) and lays two rows of 22 casings.
    Rows are spread evenly front-to-back, each occupying one channel length of depth;
    head-mark numbers sit in the flat band beyond each casing's head, so inward heads
    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
    [display-plate-top-2x22.stl, display-plate.scad]
2026-09-18 Engrave the top variant as a memorial; drop its numbers
    The chest-top plate is a memorial display, so it no longer carries per-casing
    numbers. Instead both dedications - "IN MEMORY OF ALLEN AKIN" and "SPIRIT IN THE
    SKY", the pair the funeral cartridges carried on opposite sides - are engraved
    stacked down the centre, in the flat band between the two rows, reading when you
    look down at the piece.
    markings() now branches: drawer_markings() keeps the numbers + front/back face
    text unchanged; top_markings() lays the two centred lines. Engraving only - the
    cradle geometry and fit are untouched, so a fit print in progress still holds.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
    [display-plate-top-2x22.stl, display-plate.scad]
2026-09-18 Add multi-color Prusa XL slicer project for the top plate
    stl/display-plate-top-2x22.3mf is a ready-to-print PrusaSlicer project for the
    Original Prusa XL (multi-tool, 0.4 mm nozzle), sliced multi-colour so the centre
    dedication prints in a contrasting filament against the plate body - "In Memory
    of Allen Akin" / "Spirit in the Sky" read against the plate. The .stl beside it
    serves any other printer. README and lode note it.
    [display-plate-top-2x22.3mf]
2026-09-18 Remove em-dashes from user-facing docs
    Swap every em-dash for a spaced hyphen in README.md and docs/acceptance-check.md,
    matching the hyphen style already used in the source comments and lode. Numeric
    en-dash ranges (e.g. "6 - 46 mm") are left as-is. Text only, no content change.
2026-09-18 Name the target tool chest in the README
    Both display-plate footprints are sized to a Husky 10 in. Mini 2-Drawer chest
    (Home Depot Scan Code 840146900044): the drawer plate to its 8.5" drawers, the
    top plate to its 10.75 x 6.75" lid. Noted in the README and lode so anyone can
    buy the exact chest these fit, or re-measure for another.
2026-09-18 Fix top plate for the real lid: 5.75in depth and the 8mm lip
    Two corrections from a dry fit of the chest lid:
    - The lid closes over an 8mm inward lip on every edge. The old top plate put the
    outer casings ~0.8mm under it, so the lid would not close. Added a lip keepout
    (lid_lip + lip_clr) that holds the casings back from the lid opening, with
    asserts and an echo proving the clearance. Width now 21 per row (was 22),
    clearing the lip by ~4.6mm.
    - The top is 10.75 x 5.75", not 6.75". Two rows of 63.25mm casings barely fit the
    short depth, so the rows pack tight (nearly meeting at the centre) and centre on
    the lid, clearing the lip by ~1.5mm; pullback is small so the plate cannot s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
    [display-plate-top-2x22.3mf, display-plate-top-2x22.stl, display-plate-top.stl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]
2026-09-19 Add validated multi-color 3mf for the corrected top plate
    The top plate dry-fits in the lid. Re-sliced multi-color PrusaSlicer project for
    the Original Prusa XL (cream body, orange lettering) over the corrected
    display-plate-top.stl mesh. README and lode note it ships again.
    [display-plate-top.3mf]
2026-09-19 Bring the lode current: post-delivery state
    The jig, spray stand, and both display plates are built and validated in use, so
    the roadmap collapses to the two genuinely open items (Printables listing, the
    uncommitted 28-up base). Also refresh the pieces that predated the display-plate
    work: the top summary's display-plate sentence (now two variants), the publishing
    repo layout and CC BY file list (spray-stand.scad, display-plate.scad, new STLs),
    and the lode-map description.
